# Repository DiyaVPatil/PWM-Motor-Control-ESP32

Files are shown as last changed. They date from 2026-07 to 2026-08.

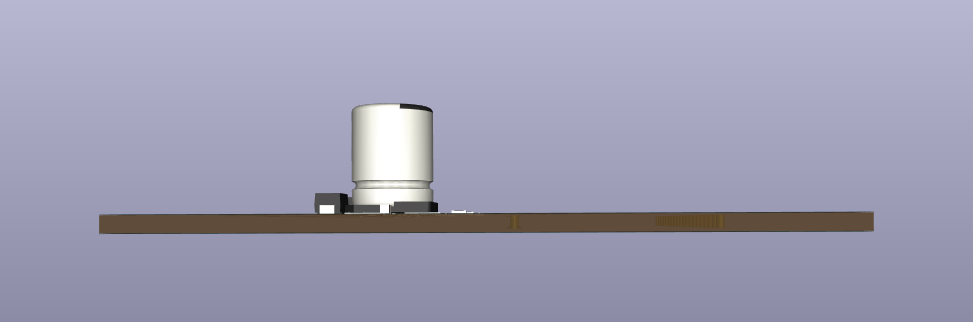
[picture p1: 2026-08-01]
images and BOM/3D_top_end.png

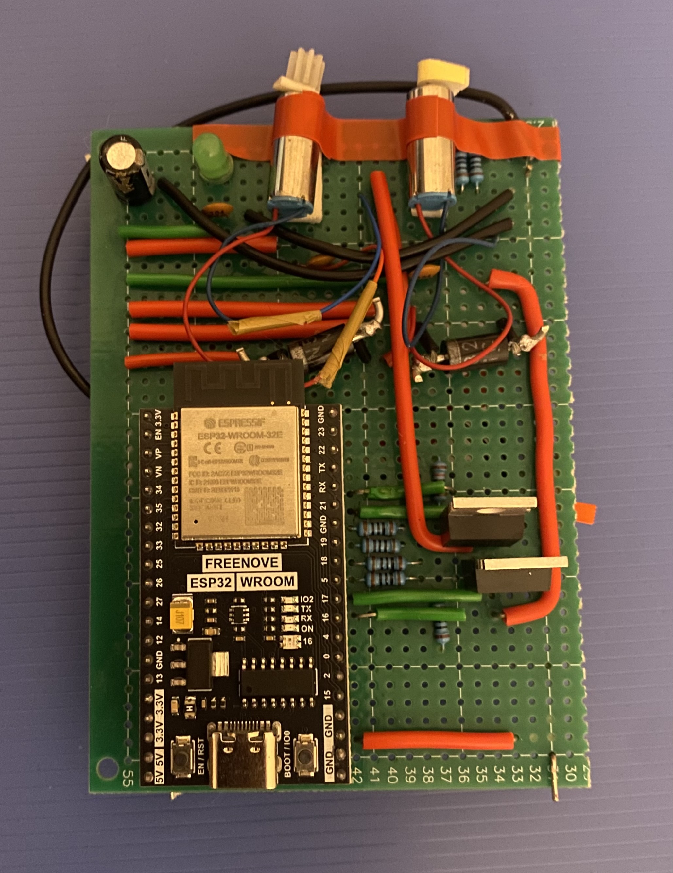
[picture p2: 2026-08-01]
images and BOM/proto_front.jpeg

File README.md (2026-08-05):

# ESP32 PWM Motor Controller
A custom PCB-based motor controller designed in KiCad for efficient PWM speed control of brushed DC motors using an ESP32 microcontroller.

This project began as a perfboard prototype and was later redesigned as a custom printed circuit board to improve physical dimensions and manufacturability.

## Features
- ESP32-based PWM motor control
- Adjustable motor speed (0–100% duty cycle)
- Logic-level MOSFET driver stage
- Flyback diode protection
- Battery-powered operation (3.7 V Li-ion)
- Compact custom PCB designed in KiCad

## Hardware
1) ESP32 DevKit | Main microcontroller 
2) IRLB8748 | Logic-level N-channel MOSFET 
3) Schottky Diode | Flyback protection 
4) TP4056 | Li-ion charging module 
5) 3.7 V Li-ion Battery | Portable power source 
6) Coreless DC Motor | Demonstration load 

## Project Timeline

### Version 1
Perfboard prototype built from KiCad schematic as a "proof-of-concept"

### Version 2
Final custom KiCad PCB, after making improvements from the perfboard prototype. 

## Future Improvements

- Real-time speed feedback on an OLED display
- Battery percentage monitoring
- Current sensing
- Bluetooth control
- Closed-loop speed control using encoder feedback

## Repository Structure
Note that there is a functionality video available under images and BOM
```
ESP32-PWM-Motor-Controller/

firmware/
hardware/
kicad/
images and BOM/
docs/
README.md
```

## Author

Diya

Electrical Engineering Student  
University of California, Riverside

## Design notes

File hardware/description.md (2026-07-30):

Note: files can be viewed on KiCad or by downloading the PDF versions. 
## PCB Design
Designed entirely using KiCad.
The design process included:

- Schematic capture
- Component selection
- Custom symbol and footprint creation 
- ERC verification
- PCB layout
- DRC verification
- Gerber & BOM generation

## Testing
The completed board was thoroughly tested using:

- Variable PWM duty cycles
- Battery operation
- Motor startup behavior
- Thermal observation
- Electrical verification 
- Functional verification
  
## Why PWM?
Pulse Width Modulation (PWM) allows motor speed to be controlled efficiently by rapidly switching the MOSFET between fully ON and fully OFF states,
with the advantage of high-efficiency motor control, reduced thermal losses, low power dissipation, extended battery runtime and smooth speed adjustment. 
This makes PWM the gold standard for Electronic speed control (ESC), hence why it's such a powerful tool when designing specifically, consumer electronics.

## Challenges
The biggest challenge was debugging hardware that appeared to have multiple faults, which ultimately traced back to a single cold solder joint.
After hours of systematically checking connections, measuring voltages, and testing components,
I learned firsthand how a small physical fault can lead to extensive debugging in hardware development.

The project also required careful power management, MOSFET selection, flyback protection,
and the transition from a hand-wired perfboard prototype to a verified KiCad PCB.

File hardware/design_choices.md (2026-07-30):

# Design Decisions

## Objective
Designed as a compact, battery-powered PWM motor controller for small brushed drone motors,
with an emphasis on efficiency, wireless control, and future scalability.

## ESP32
Chosen for its integrated Wi-Fi, enabling a custom browser-based dashboard without additional communication hardware.
Its hardware PWM peripherals provide reliable motor control, while the large number of GPIO pins allows future expansion for
sensors, displays, and additional peripherals.

## Initial Prototype

### IRLB8748 MOSFET
Selected for its low RDS(on) and high current capability, providing efficient PWM switching with minimal conduction losses during prototyping.

### Schottky Flyback Diode
Added to suppress inductive voltage spikes generated by the motors, protecting the switching circuitry and improving overall reliability.

### Decoupling Capacitors
A 470 µF capacitor stabilizes the motor supply during rapid load changes,
while 0.1 µF ceramic capacitors filter high-frequency switching noise for stable operation  near the power sources and motors.
Capacitors placed as close as possible to the noise sources to effectively smoothen signals. 

## Final Design Improvements

### AO3400A MOSFET
Replaced the IRLB8748 (THT-Package) with the AO3400A (SMD-Package) to significantly reduce PCB size while maintaining efficient switching performance,
making the design better suited for compact, battery-powered applications.

### TPS63031 Buck-Boost Converter
Added to provide a regulated supply from a single-cell 3.7V Li-ion battery to the ESP32 and the motors. 
The TPS63031 boosts the 3.7V to 5V for the ESP, while the motors still run on the 3.7V directly from the battery. 
Eliminates the need to power the ESP with USB and make the board independent, once code is uploaded to the ESP.

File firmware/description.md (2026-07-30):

# Firmware

The ESP32 firmware provides wireless, browser-based control of two DC motors using PWM.

## Software Used

- **C++** — ESP32 firmware using the Arduino framework, uses the WiFi.h library to create a Wi-Fi access point hosted by the ESP32 and 
            WebServer.h to handles HTTP requests from the control dashboard.
- **HTML/CSS** — Builds and styles the web interface
- **JavaScript** — Sends motor control commands to the ESP32
- **LEDC PWM** — Generates 5 kHz, 8-bit PWM signals for motor speed control

## Functionality

The ESP32 hosts a local web dashboard where users can independently:

- Adjust Motor A and Motor B speed from 0–100%
- Start and stop each motor
- Control the motors wirelessly through a web browser

The dashboard communicates with the ESP32 through HTTP requests, which the firmware converts into PWM outputs for the motor control circuitry.

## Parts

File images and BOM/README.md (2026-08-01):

# Images & BOM

This directory contains visual documentation of the project throughout its development and the final BOM.

## Contents

- PCB 3D renders
- Perfboard prototype
- BOM file for the final prototype
Note that the 2*20 THT holes on the 3D image are to mount the ESP-WROOM-32E DevKit and the blanks are screw terminals for motor and battery connections.

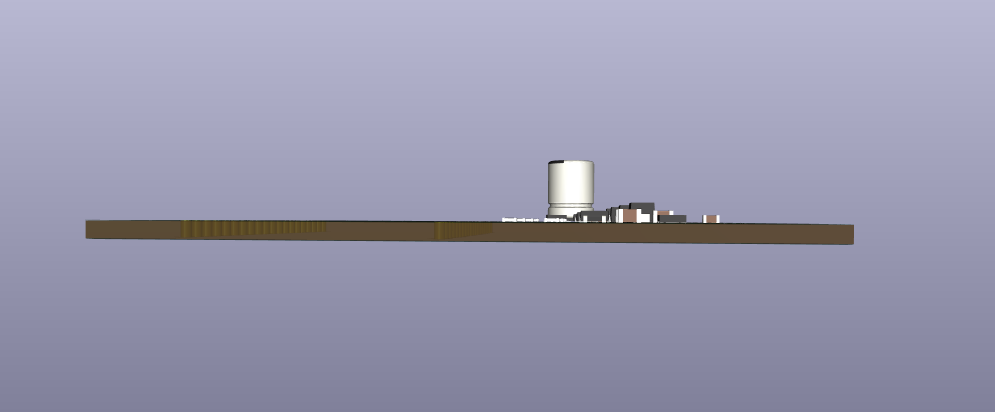
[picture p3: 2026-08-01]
images and BOM/3D_bottom_end.png

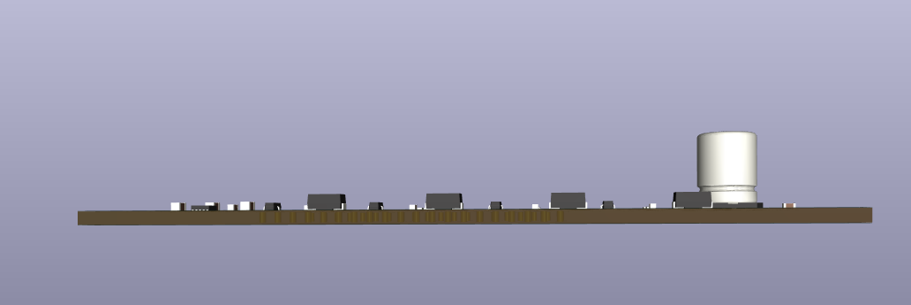
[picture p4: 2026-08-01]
images and BOM/3D_right.png

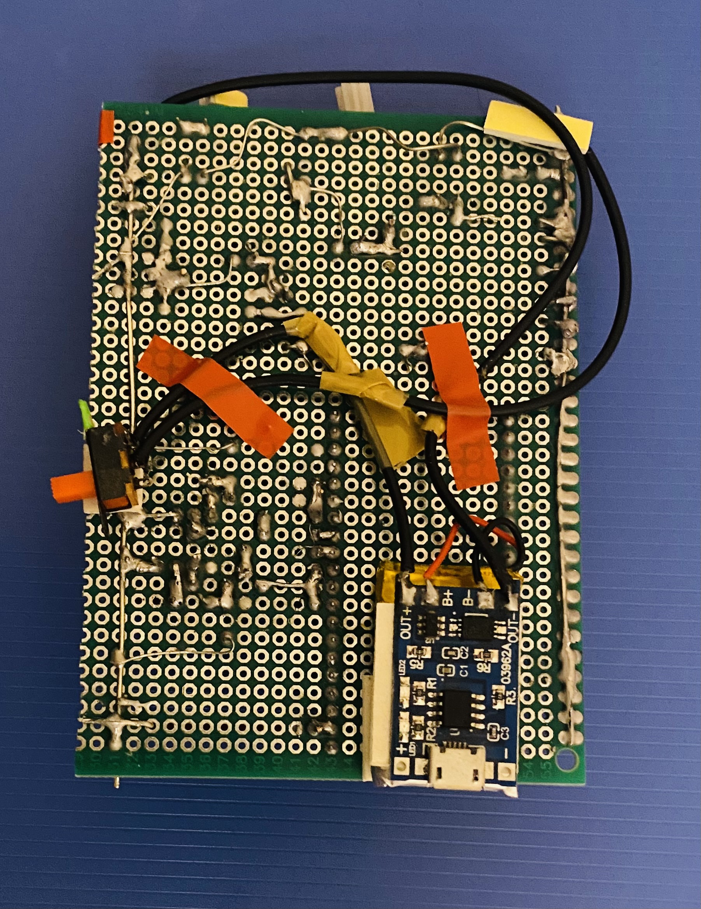
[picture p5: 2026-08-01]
images and BOM/proto_back.jpeg

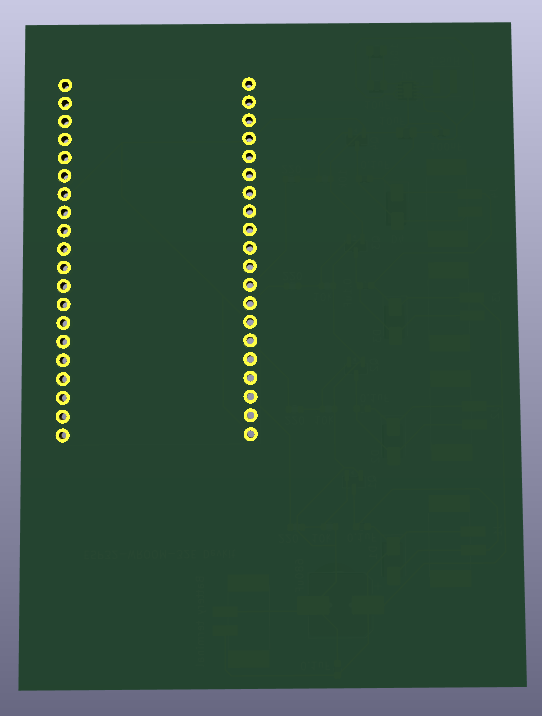
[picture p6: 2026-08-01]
images and BOM/3D_back.png

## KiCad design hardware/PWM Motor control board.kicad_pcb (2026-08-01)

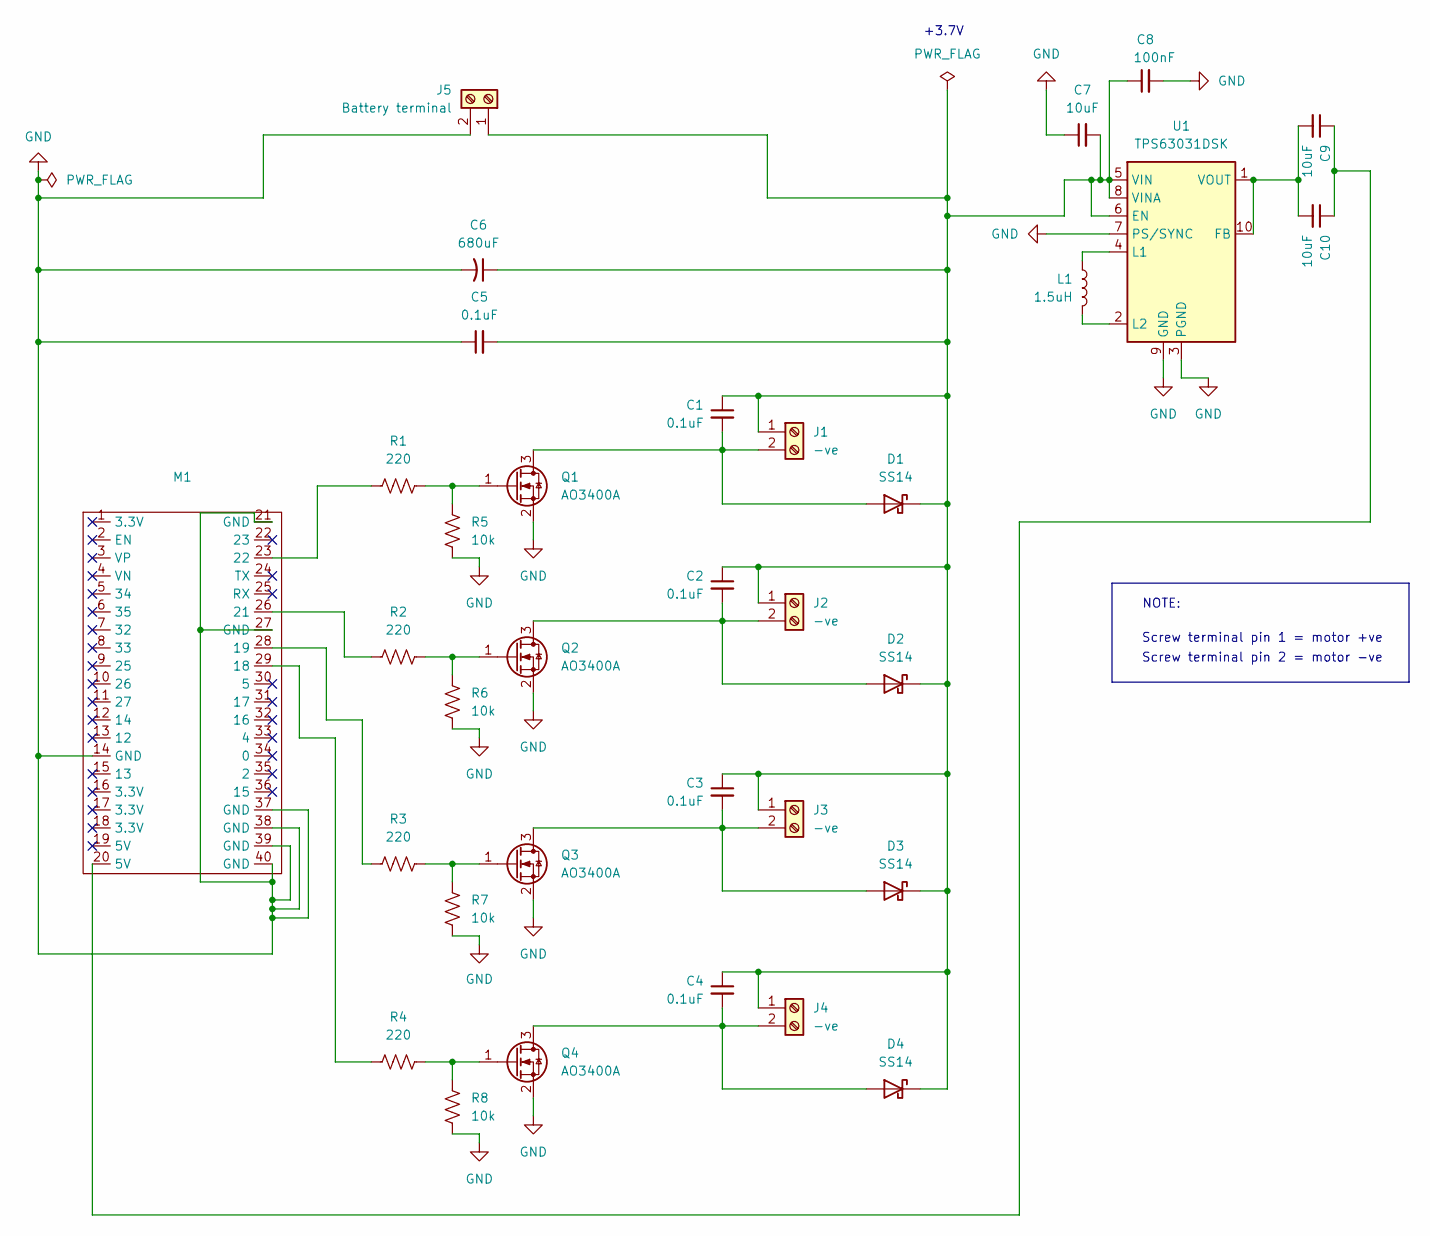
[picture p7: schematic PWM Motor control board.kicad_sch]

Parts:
C1, C2, C3, C4, C5: 0.1uF; C_0603_1608Metric
C6: 680uF; CP_Elec_8x10.5
C7, C9, C10: 10uF; C_0805_2012Metric
C8: 100nF; C_0603_1608Metric
D1, D2, D3, D4: SS14; D_SMA
J1, J2, J3, J4: -ve; TerminalBlock_Phoenix_PTSM-0,5-2-2,5-V-SMD_1x02-1MP_P2.50mm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
J5: Battery terminal; TerminalBlock_Phoenix_PTSM-0,5-2-2,5-V-SMD_1x02-1MP_P2.50mm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
L1: 1.5uH; L_Coilcraft_XxL4020
M1: Untitled
Q1, Q2, Q3, Q4: AO3400A; SOT-23
R1, R2, R3, R4: 220; R_0603_1608Metric
R5, R6, R7, R8: 10k; R_0603_1608Metric
U1: TPS63031DSK; WSON-10-1EP_2.5x2.5mm_P0.5mm_EP1.2x2mm

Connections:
GND: C5.1, C6.2, C7.1, C8.2, J5.2, M1.14 (GND), M1.21 (GND), M1.27 (GND), M1.37 (GND), M1.38 (GND), M1.39 (GND), M1.40 (GND), Q1.2 (S), Q2.2 (S), Q3.2 (S), Q4.2 (S), R5.2, R6.2, R7.2, R8.2, U1.3 (PGND), U1.7 (PS/SYNC), U1.9 (GND), U1.11 (PGND)
unnamed: C9.1, C10.1, M1.20 (5V)
unnamed: C1.2, D1.2 (A), J1.2, Q1.3 (D)
unnamed: C1.1, C2.1, C3.1, C4.1, C5.2, C6.1, C7.2, C8.1, D1.1 (K), D2.1 (K), D3.1 (K), D4.1 (K), J1.1, J2.1, J3.1, J4.1, J5.1, U1.5 (VIN), U1.6 (EN), U1.8 (VINA)
unnamed: C2.2, D2.2 (A), J2.2, Q2.3 (D)
unnamed: C3.2, D3.2 (A), J3.2, Q3.3 (D)
unnamed: C4.2, D4.2 (A), J4.2, Q4.3 (D)
unnamed: M1.29 (18), R4.1
unnamed: M1.28 (19), R3.1
unnamed: M1.26 (21), R2.1
unnamed: M1.23 (22), R1.1
unnamed: Q1.1 (G), R1.2, R5.1
unnamed: Q2.1 (G), R2.2, R6.1
unnamed: Q3.1 (G), R3.2, R7.1
unnamed: Q4.1 (G), R4.2, R8.1
unnamed: C9.2, C10.2, U1.1 (VOUT), U1.10 (FB)
unnamed: L1.2, U1.4 (L1)
unnamed: L1.1, U1.2 (L2)

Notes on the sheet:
Screw terminal pin 1 = motor +ve
+3.7V
Screw terminal pin 2 = motor -ve
NOTE:

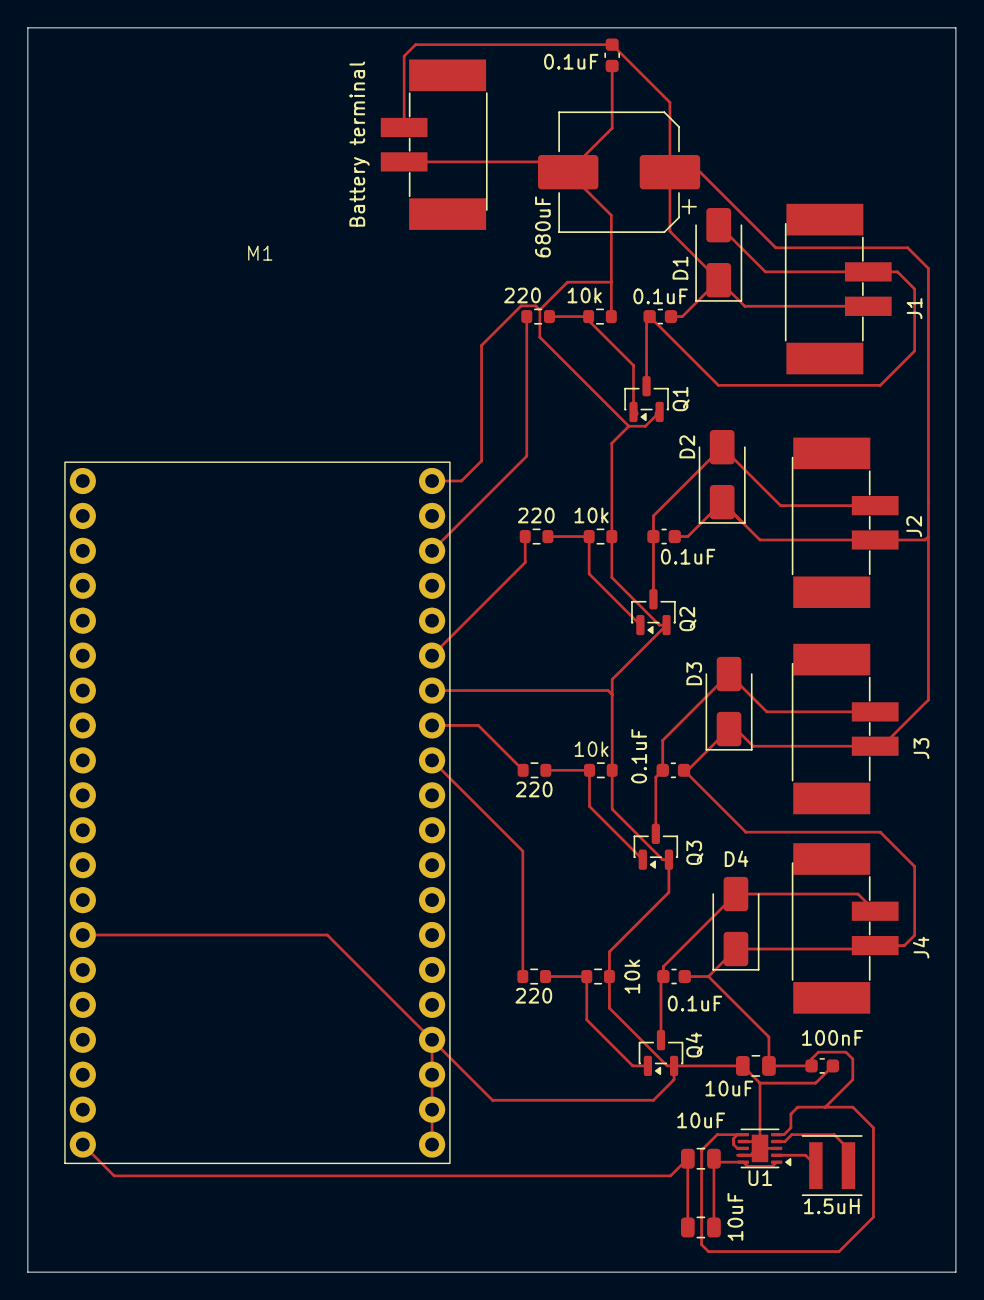
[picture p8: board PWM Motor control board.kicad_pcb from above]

Board: 2 copper layers, 67.5 x 90.5 mm, 34 parts (0 on the bottom side), 18 nets.

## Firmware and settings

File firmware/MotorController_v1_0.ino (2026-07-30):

#include <WiFi.h>
#include <WebServer.h>

const char* ssid="MotorDashboard";
const char* password="ESP32";

WebServer server(80);

const int MOTOR_A_PIN=18;
const int MOTOR_B_PIN=19;

int motorAPercent=0;
int motorBPercent=0;
bool motorARunning=false;
bool motorBRunning=false;

void writeMotorA(){
  int pwm = motorARunning ? map(motorAPercent,0,100,0,255):0;
  ledcWrite(MOTOR_A_PIN,pwm);
}
void writeMotorB(){
  int pwm = motorBRunning ? map(motorBPercent,0,100,0,255):0;
  ledcWrite(MOTOR_B_PIN,pwm);
}

void setup(){
  Serial.begin(115200);
  ledcAttach(MOTOR_A_PIN,5000,8);
  ledcAttach(MOTOR_B_PIN,5000,8);

  WiFi.softAP(ssid,password);

  server.on("/setA",[](){
    motorAPercent=constrain(server.arg("value").toInt(),0,100);
    writeMotorA();
    server.send(200,"text/plain","OK");
  });

  server.on("/setB",[](){
    motorBPercent=constrain(server.arg("value").toInt(),0,100);
    writeMotorB();
    server.send(200,"text/plain","OK");
  });

  server.on("/startA",[](){motorARunning=true;writeMotorA();server.send(200,"text/plain","OK");});
  server.on("/stopA",[](){motorARunning=false;writeMotorA();server.send(200,"text/plain","OK");});
  server.on("/startB",[](){motorBRunning=true;writeMotorB();server.send(200,"text/plain","OK");});
  server.on("/stopB",[](){motorBRunning=false;writeMotorB();server.send(200,"text/plain","OK");});

server.on("/", []()
{

server.send(200,"text/html",R"rawliteral(

<!DOCTYPE html>
<html>

<head>

<meta charset="UTF-8">

<title>ESP32 Motor Dashboard</title>

<style>

body{

background:#181818;
font-family:Arial;
color:white;

display:flex;

justify-content:center;

padding-top:40px;

}

.card{

width:500px;

background:#252525;

padding:30px;

border-radius:18px;

box-shadow:0 0 25px rgba(0,0,0,.5);

}

h1{

text-align:center;

margin-bottom:30px;

}

.motor{

margin-bottom:40px;

}

.slider{

width:100%;

}

.percent{

font-size:30px;

font-weight:bold;

text-align:center;

margin-bottom:10px;

}

.number{

width:80px;

font-size:20px;

text-align:center;

margin-top:10px;

}

.buttons{

margin-top:15px;

}

button{

padding:10px 20px;

border:none;

border-radius:8px;

font-size:16px;

cursor:pointer;

margin-right:10px;

}

.start{

background:#18b318;

color:white;

}

.stop{

background:#d22;

color:white;

}

</style>

</head>

<body>

<div class="card">

<h1>Motor Dashboard</h1>

<div class="motor">

<h2>Motor A</h2>

<div class="percent">

<span id="aValue">0</span>%

</div>

<input

class="slider"

type="range"

min="0"

max="100"

value="0"

id="sliderA">

<br>

<input

class="number"

type="number"

min="0"

max="100"

value="0"

id="numberA">

<div class="buttons">

<button class="start" onclick="startA()">START</button>

<button class="stop" onclick="stopA()">STOP</button>

</div>

</div>

<hr>

<div class="motor">

<h2>Motor B</h2>

<div class="percent">

<span id="bValue">0</span>%

</div>

<input

class="slider"

type="range"

min="0"

max="100"

value="0"

id="sliderB">

<br>

<input

class="number"

type="number"

min="0"

max="100"

value="0"

id="numberB">

<div class="buttons">

<button class="start" onclick="startB()">START</button>

<button class="stop" onclick="stopB()">STOP</button>

</div>

</div>

</div>

<script>

const sliderA=document.getElementById("sliderA");
const sliderB=document.getElementById("sliderB");

const numberA=document.getElementById("numberA");
const numberB=document.getElementById("numberB");

sliderA.oninput=function(){

numberA.value=this.value;

document.getElementById("aValue").innerHTML=this.value;

fetch("/setA?value="+this.value);

}

numberA.oninput=function(){

sliderA.value=this.value;

document.getElementById("aValue").innerHTML=this.value;

fetch("/setA?value="+this.value);

}

sliderB.oninput=function(){

numberB.value=this.value;

document.getElementById("bValue").innerHTML=this.value;

fetch("/setB?value="+this.value);

}

numberB.oninput=function(){

sliderB.value=this.value;

document.getElementById("bValue").innerHTML=this.value;

fetch("/setB?value="+this.value);

}

function startA(){

fetch("/startA");

}

function stopA(){

fetch("/stopA");

}

function startB(){

fetch("/startB");

}

function stopB(){

fetch("/stopB");

}

</script>

</body>

</html>

)rawliteral");

});

  server.begin();
}

void loop(){
  server.handleClient();
}
